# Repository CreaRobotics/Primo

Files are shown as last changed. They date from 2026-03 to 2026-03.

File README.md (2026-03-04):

<p allign="center">
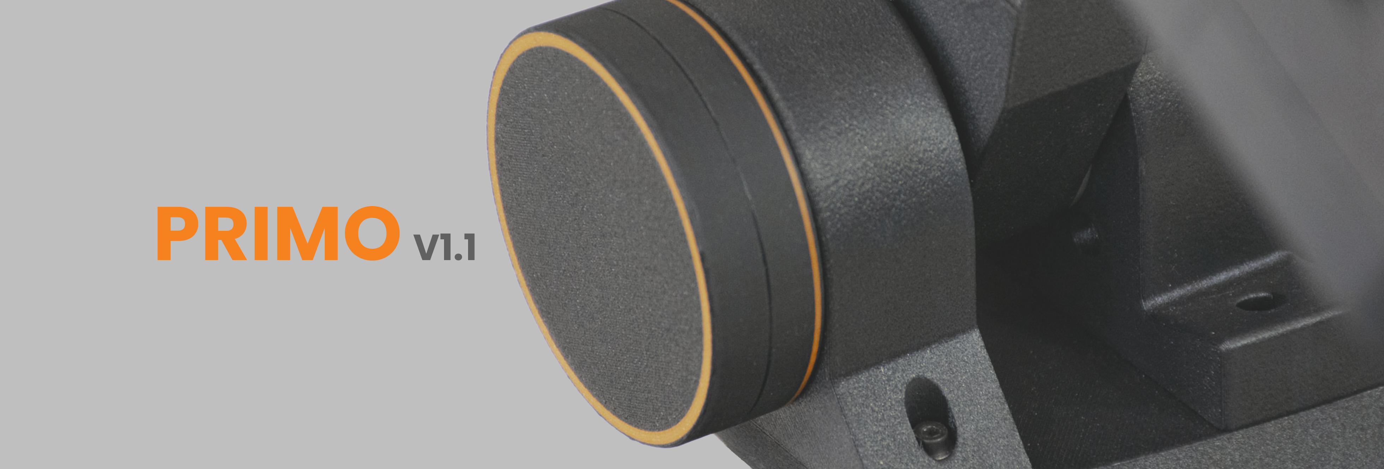
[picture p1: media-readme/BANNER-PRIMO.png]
Primo v1.1 Your first friendly robotic arm
 
</p>



# Manipolatore Antropomorfo 
Primo è il nostro manipolatore antropomorfo interamente stampato in 3d, progettato e realizzato da [Crea3D](https://www.crea3d.com/it/) per il settore STEM.
### 🦾Caratteristiche Principali <!-- (v0.0) -->

* **6 Gradi di Libertà (6 DOF):** Manipolatore a catena cinematica aperta, ispirato ai robot industriali.
* **Riduttori armonici:**  Garantiscono movimenti fluidi ad alta precisione.
* **Open Hardware:** File STL disponibili per la stampa 3D <!-- (consigliato PPS-CF o PLA rinforzato) -->.
* **Elettronica Accessibile:** Basato su Duet per una facile programmazione.
* **Compatibilità Software:** Supporta interfacce di programmazione software di simulazione professionali come **RoboDK**.
* **Modulare:** Facile da assemblare, riparare e modificare.

## 🔖Descrizione 

Primo è un braccio robotico a 6 assi open source interamente realizzato utilizzando la stampa 3d. Progettato a scopo educativo e formativo, con l' obiettivo di far scoprire il mondo della robotica a tutti, dando la possibilità di mettere in campo i concetti chiave

### 🔍 Cosa trovo in questa repository ?
 
 In questa repository troverai tutto il materiale necessario a ricreare Primo. Nelle varie cartelle troverai tutti i file CAD che permettono la stampa della struttura meccanica, le liste di componenti sia meccanici che elettrici, e i diagrammi delle connessioni e i software necessari.

* **01-CAD**: Contiene i file per la stampa 3D e i manuali di montaggio. 
* **02-BOM:** Liste componenti (BOM) meccanici ed elettrici
* **03-Digital Twin:** Contiene il modello gemello digitale per poterlo utilizzare con RoboDk. 
* **04-OS:** Contiene i file necessari a montare l'immagine dell'OS sul Raspberry Pi, precaricata con tutti i tool e le configurazioni necessarie.

### ⬇️ Dove posso trovare i file di stampa ?

Puoi trovare i file ufficiali anche sulle piattaforme:

👉 **[MakerWorld](https://makerworld.com/it/models/2473047-primo-v1-1-6-dof-robotic-arm#profileId-2715454)**

👉 **[Printables](https://www.printables.com/?lang=it)**

#### E se qualcosa va storto 🤕?
Se un pezzo stampato dovesse rompersi, nessun problema, grazie ai file a disposizione, puoi semplicemente ristamparlo in autonomia, senza dover attendere pezzi di ricambio o contattare l'assistenza.

Nella cartella 01-CAD troverai sia i file STL, ideali se vuoi sperimentare con parametri di stampa e materiali diversi,  già ottimizzati e pronti per essere stampati.

## 🚀 Per Iniziare

#### 📖 Documentazione

La documentazione completa, le guide di montaggio e la configurazione software, è disponibile qui: 

👉 **[Manuale Ufficiale PRIMO](https://crearobotics.github.io/PRIMO-Docs/cos_e_la_robotica/)**

#### 🛠️ Assemblaggio

Le istruzioni passo-passo per l'assemblaggio meccanico ed elettronico sono dettagliate nella nostra documentazione ufficiale.

* [Guida all'assemblaggio meccanico](https://crearobotics.github.io/PRIMO-Docs/)
* [Schema collegamenti elettronici](https://crearobotics.github.io/PRIMO-Docs/)

Oppure segui i video passo passo sul nostro canale [YouTube](https://www.youtube.com/@CreaRobotics).

## 🤝 Contribuisci

PRIMO è un progetto vivo. Sentiti libero di aprire *Issues* per segnalare problemi o *Pull Requests* per proporre miglioramenti ai file CAD o al codice. 

<!--Oppure scrivi una mail a: (mettere la mail)-->

# ⚠️ Avvertenze di Sicurezza 

Prima di assemblare o utilizzare PRIMO, leggere attentamente le seguenti direttive di sicurezza.
###### **Installazione Stabile:** Assicurarsi che il robot sia installato correttamente su una superficie solida e stabile, con spazio sufficiente attorno per evitare urti e collisioni durante il movimento. 

######  **Comportamento in Emergenza:** Il taglio dell'alimentazione o l'attivazione del pulsante di arresto di emergenza (E-Stop) possono causare un leggero abbassamento del braccio. Sebbene questo movimento sia ammortizzato, **non toccare il robot** mentre si attiva l'arresto di emergenza per evitare schiacciamenti o collisioni.

###### **Ambiente di Utilizzo:** Non utilizzare il robot in ambienti non idonei (es. all'aperto). Non installare PRIMO in ambienti umidi, vicino all'acqua o in ambienti pericolosi (es. presenza di gas infiammabili)..

###### **Calore e Temperatura:** Il robot e i motori generano calore durante il funzionamento. Non toccare o maneggiare il robot (in particolare la zona motori) durante l'operazione o subito dopo un uso prolungato: le alte temperature possono causare scottature. 

###### **Distanza di Sicurezza:** Quando PRIMO è attivo, mantenere una distanza di sicurezza dalle parti in movimento. Assicurarsi che il **pulsante di arresto di emergenza** sia sempre in una posizione facile e rapida da raggiungere per prevenire infortuni.

*Progettato e realizzato con il ❤️ da [Crea3d](https://www.crea3d.com/it/).*

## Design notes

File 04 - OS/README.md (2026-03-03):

## CONFIGURAZIONE
Nella cartella *Config* trovi tutto il necessario a configurare correttamente il Raspberry. Abbiamo predisposto una piccola guida e tutti i file necessari a crare correttamente una configurazione completa del softwere.

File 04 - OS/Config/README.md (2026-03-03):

# Configurazione

Questa procedura permette di installare la configurazione completa (configurazione base, macro e demo) su una microSD che contiene già Duet Web Control (DWC) e Duet Software Framework (DSF).

⚠️ Non eliminare la cartella `/www`, che contiene l’interfaccia web.

## Cosa ti serve

- La microSD della Duet
- Un PC con lettore microSD
- Il pacchetto di configurazione fornito

## Procedura guidata

### 1 - Spegni la Duet

Spegnere completamente l’alimentazione prima di rimuovere la microSD.

### 2 - Inserisci la microSD nel PC

- Rimuovi la microSD dalla Duet
- Inseriscila nel PC
- Se presente un file immagine, montalo per accedere al filesystem

### 3 - Naviga nel filesystem corretto

Se stai lavorando su una microSD con sistema Linux (DSF), segui questo percorso:

```
rootfs
 └── opt
     └── dsf
         └── sd
```

La cartella `sd` rappresenta la root effettiva della scheda SD vista da RepRapFirmware.

Apri quindi la cartella:

```
rootfs/opt/dsf/sd
```

### 4 - Verifica la struttura

All’interno della cartella `sd` dovresti trovare:

```
/sys
/macros
/gcodes
/www
```

⚠️ La cartella `/www` contiene Duet Web Control e non deve essere eliminata.

### 5 - Copia i file di configurazione

Dal pacchetto fornito:

- Copia la cartella `/sys`
- Copia la cartella `/macros`
- Copia la cartella `/gcodes` (se presente)

Incollale dentro:

```
rootfs/opt/dsf/sd
```

Quando richiesto:

✔ Conferma la sovrascrittura

❌ Non eliminare o modificare la cartella `/www`

### 6 - Smonta ed espelli in sicurezza

- Chiudi eventuali file aperti
- Espelli correttamente la microSD
- Rimuovila dal PC

### 7 - Reinserisci la microSD nella Duet

- Inserisci la scheda
- Accendi la Duet

Collegandoti via browser all’indirizzo IP della macchina troverai:

- Configurazione già attiva
- Macro operative disponibili
- File demo caricati
- Interfaccia DWC funzionante

## ⚠️ Controlli al primo avvio

Prima di eseguire programmi automatici:

- Verifica verso degli assi
- Controlla finecorsa
- Esegui piccoli movimenti manuali di test

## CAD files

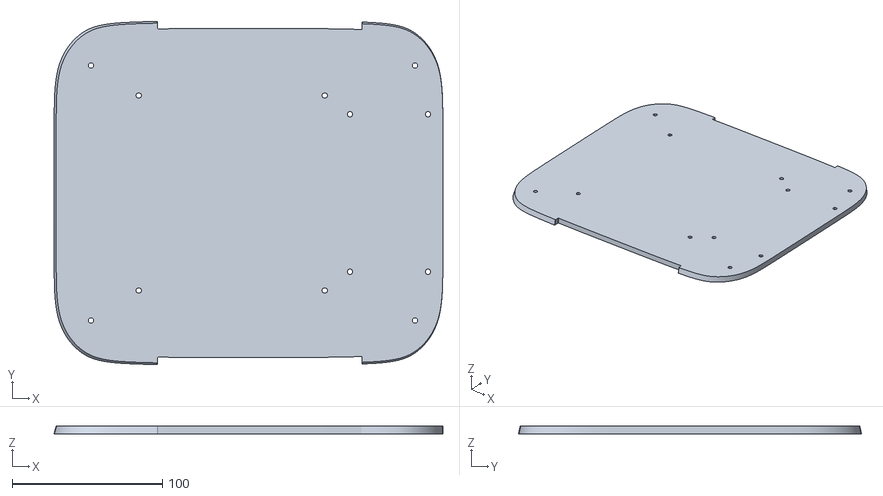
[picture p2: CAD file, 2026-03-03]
01 - CAD/02 - STL/01-BASE/STL/PRM_V11_AM3_BAS_002_R00.stl
259.3 x 228.8 x 5.00

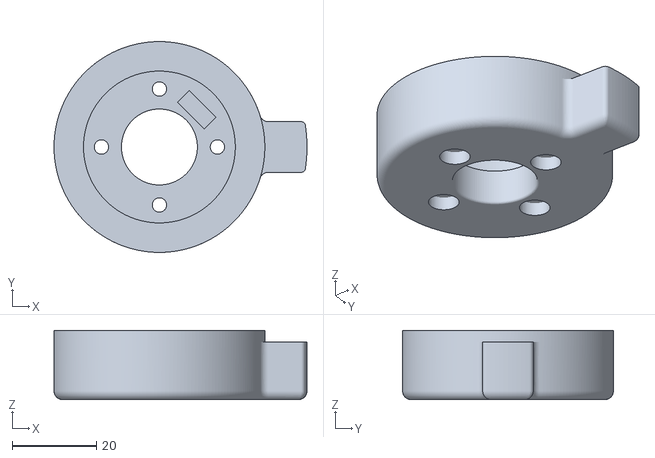
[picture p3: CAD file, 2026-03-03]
01 - CAD/02 - STL/02-SHOULDER/STL/PRM-V11-AM3-SHD-005-R00.stl
60.0 x 50.0 x 16.4

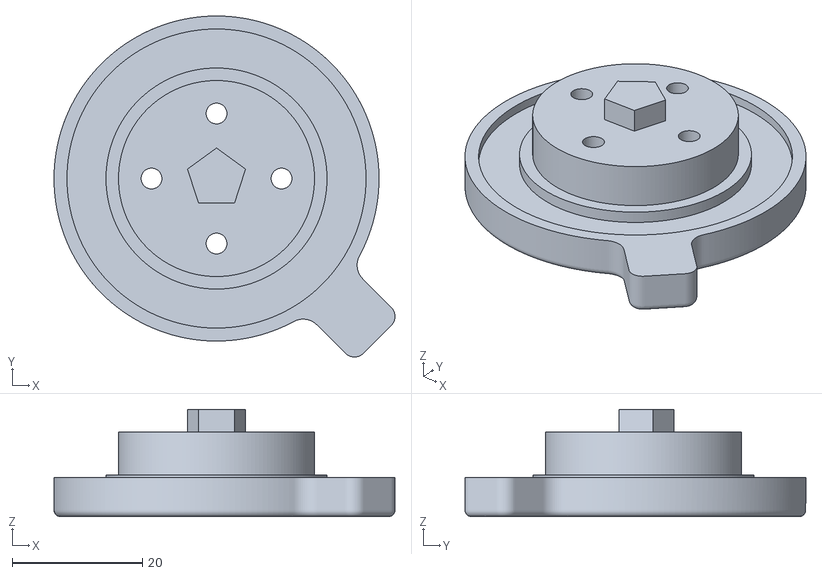
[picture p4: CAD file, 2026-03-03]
01 - CAD/02 - STL/03-ARM/STL/PRM-V11-AM3-ARM-009-R00.stl
52.4 x 52.5 x 16.5

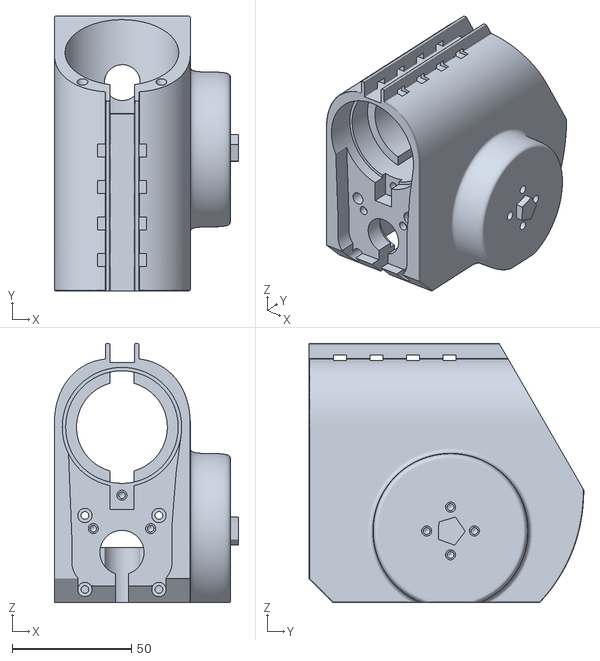
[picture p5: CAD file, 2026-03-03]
01 - CAD/02 - STL/04-ELBOW/STL/PRM-V11-AM3-ELB-001-R00.stl
77.2 x 115.0 x 108.5

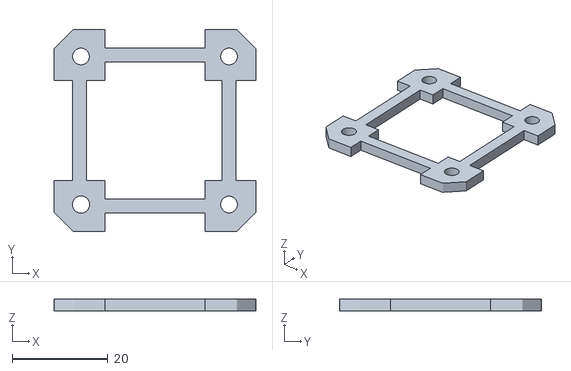
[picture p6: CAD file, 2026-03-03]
01 - CAD/02 - STL/05-FOREARM/STL/PRM_V11_AM3_FAM_003_R00.stl
42.3 x 42.3 x 2.50

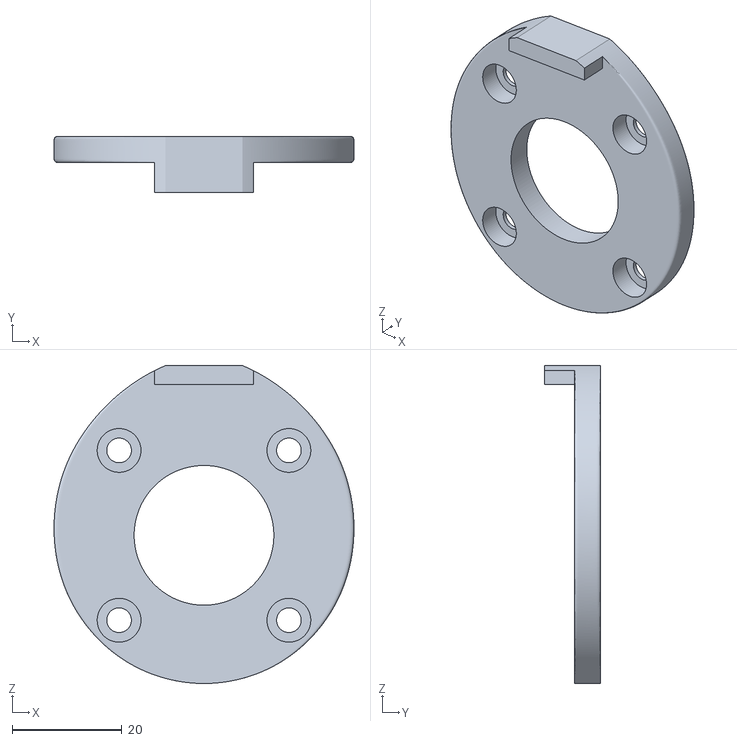
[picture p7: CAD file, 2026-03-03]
01 - CAD/02 - STL/06-WRIST/STL/PRM_V11_AM3_WRS_002_R00.stl
54.8 x 10.3 x 58.1

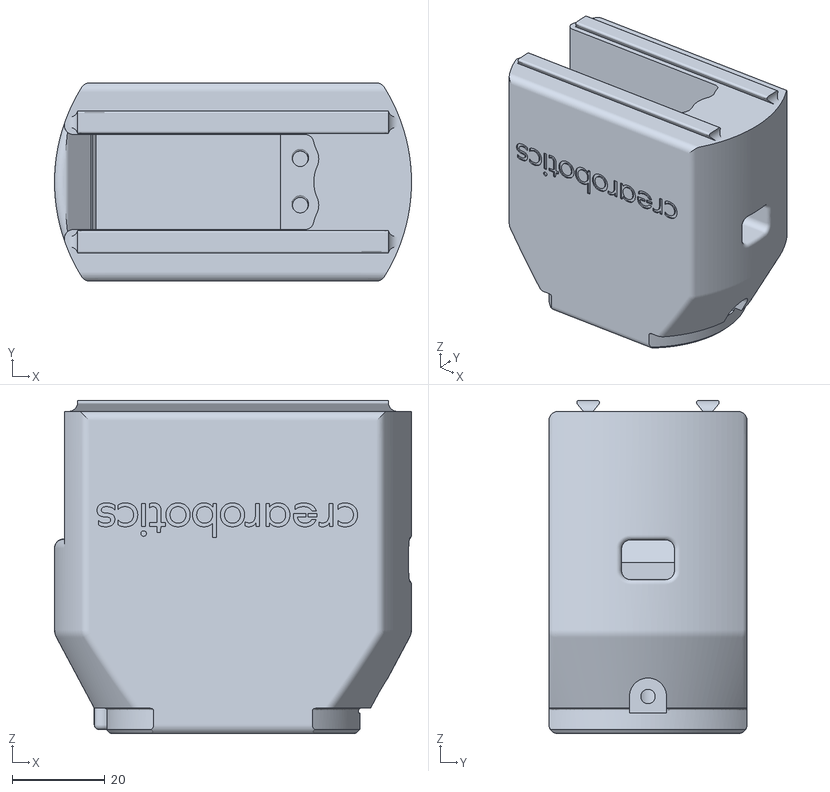
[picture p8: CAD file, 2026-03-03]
01 - CAD/02 - STL/07-EOT/STL/PRM-V11-AM3-EOT-001-R00.stl
77.0 x 42.8 x 71.9

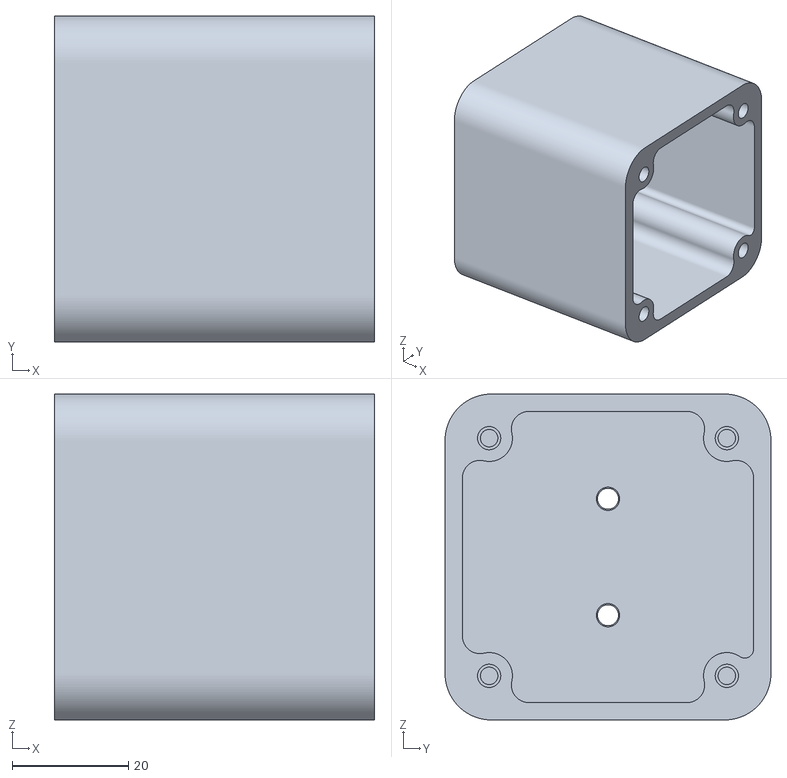
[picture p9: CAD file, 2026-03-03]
01 - CAD/02 - STL/01-BASE/STL/PRM_V11_AM3_BAS_011_R00.stl
55.0 x 56.0 x 56.0

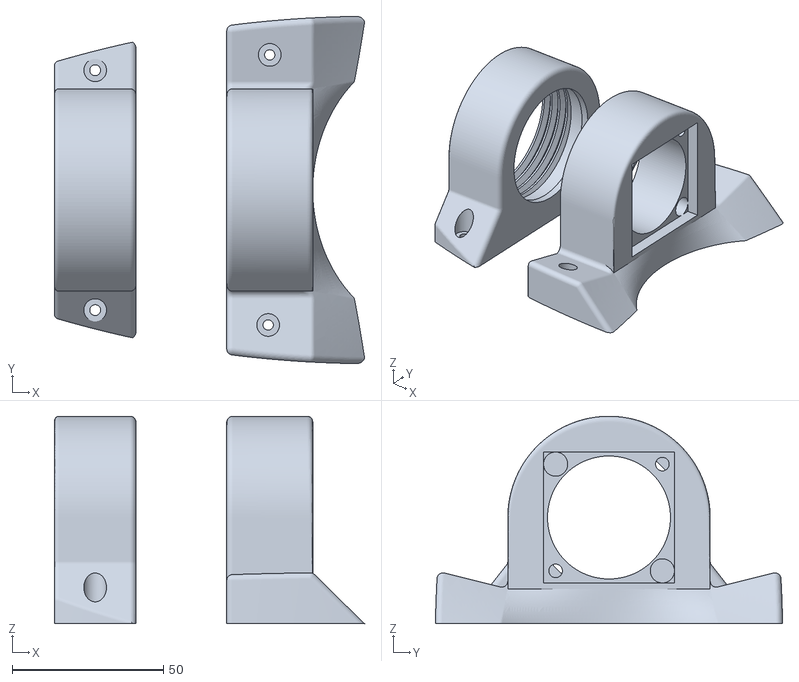
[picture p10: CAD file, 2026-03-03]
01 - CAD/02 - STL/02-SHOULDER/STL/PRM-V11-AM3-SHD-002-R00.stl
102.6 x 114.9 x 68.7

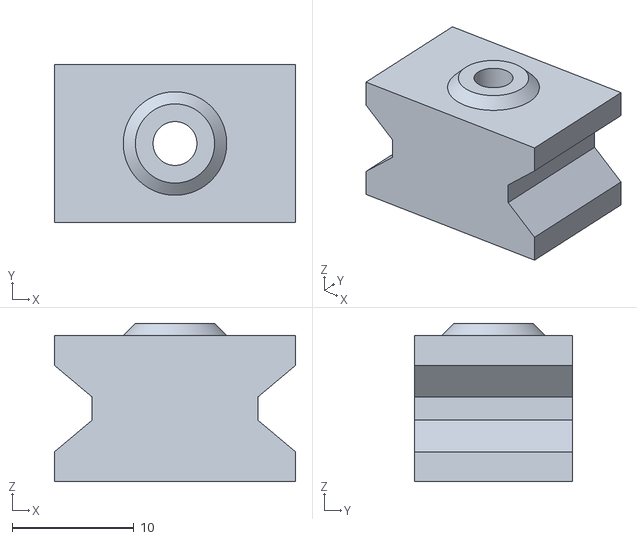
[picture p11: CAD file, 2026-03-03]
01 - CAD/02 - STL/03-ARM/STL/PRM-V11-AM3-ARM-007-R00.stl
19.8 x 13.0 x 13.0

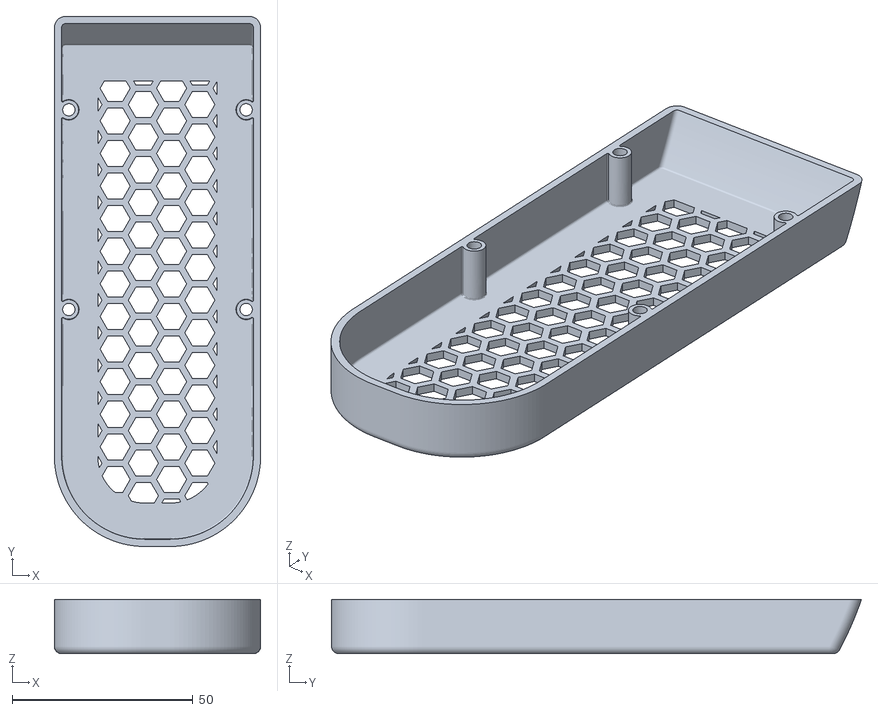
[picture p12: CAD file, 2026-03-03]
01 - CAD/02 - STL/05-FOREARM/STL/PRM_V11_AM3_FAM_005_R00.stl
57.0 x 146.4 x 15.0

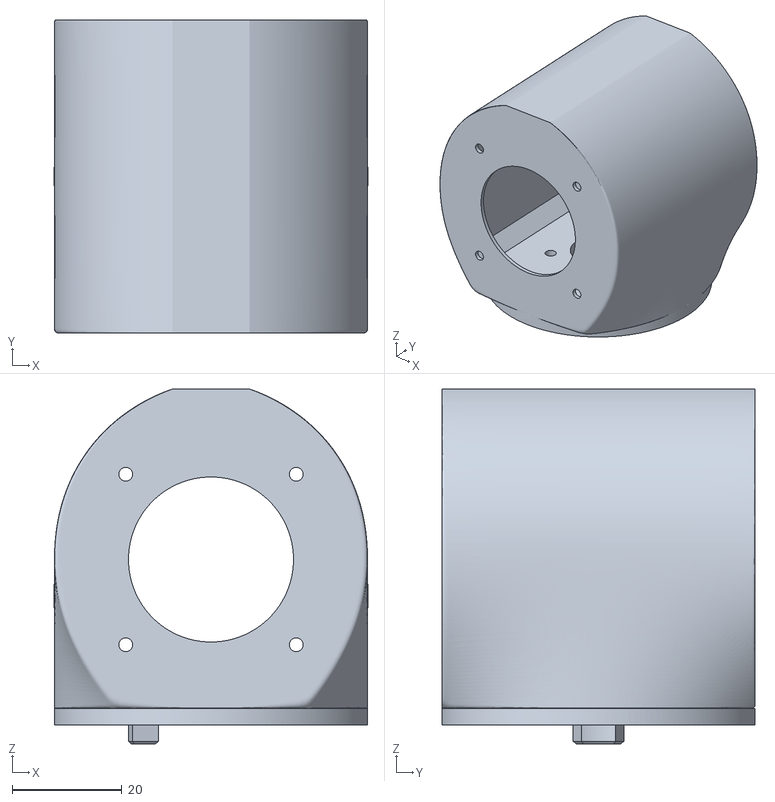
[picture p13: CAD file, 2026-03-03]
01 - CAD/02 - STL/06-WRIST/STL/PRM_V11_AM3_WRS_001_R00.stl
57.0 x 57.0 x 64.6

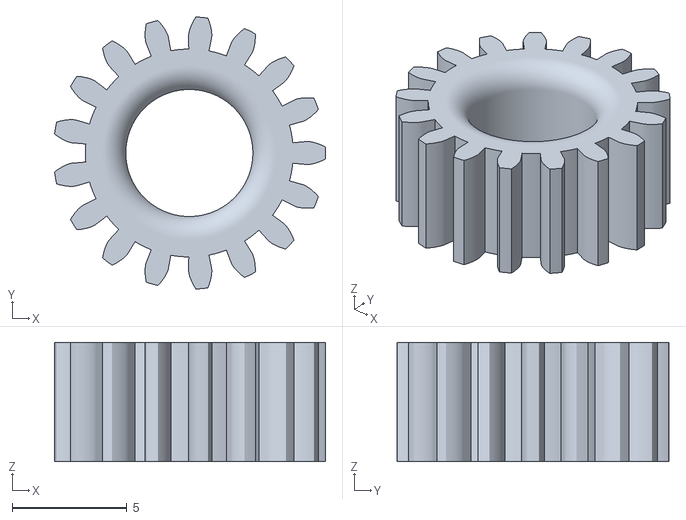
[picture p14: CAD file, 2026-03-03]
01 - CAD/02 - STL/07-EOT/STL/PRM-V11-AM3-EOT-002-R00.stl
11.8 x 11.8 x 5.20

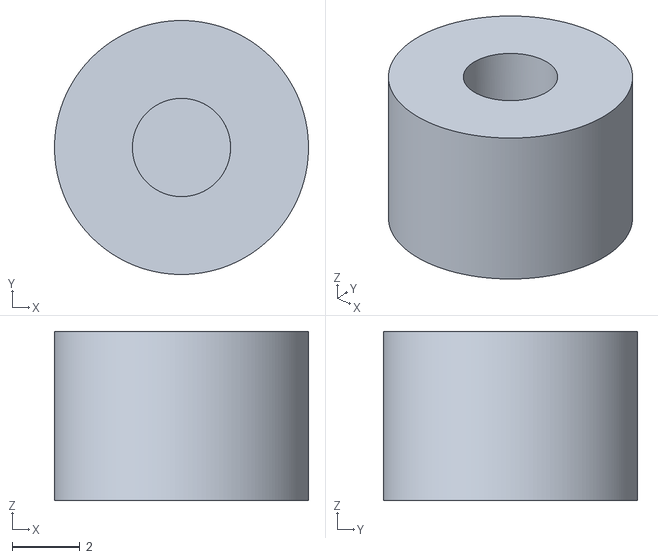
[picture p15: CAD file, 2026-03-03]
01 - CAD/02 - STL/01-BASE/STL/PRM_V11_AM3_BAS_009_R00.stl
7.50 x 7.50 x 5.00

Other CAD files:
01 - CAD/02 - STL/04-ELBOW/STL/PRM-V11-AM3-ELB-003-R00.stl
01 - CAD/02 - STL/02-SHOULDER/STL/PRM-V11-AM3-SHD-003-R00.stl
01 - CAD/02 - STL/03-ARM/STL/PRM-V11-AM3-ARM-003-R00.stl
01 - CAD/02 - STL/04-ELBOW/STL/PRM-V11-AM3-ELB-004-R00.stl
01 - CAD/02 - STL/01-BASE/STL/PRM_V11_AM3_BAS_003_R00.stl
01 - CAD/02 - STL/01-BASE/STL/PRM_V11_AM3_BAS_004_R00.stl
01 - CAD/02 - STL/01-BASE/STL/PRM_V11_AM3_BAS_005_R00.stl
01 - CAD/02 - STL/01-BASE/STL/PRM_V11_AM3_BAS_006_R00.stl
01 - CAD/02 - STL/01-BASE/STL/PRM_V11_AM3_BAS_007_R00.stl
01 - CAD/02 - STL/01-BASE/STL/PRM_V11_AM3_BAS_008_R00.stl
01 - CAD/02 - STL/01-BASE/STL/PRM_V11_AM3_BAS_010_R00.stl
01 - CAD/02 - STL/01-BASE/STL/PRM_V11_AM3_BAS_012_R00.stl
01 - CAD/02 - STL/01-BASE/STL/PRM_V11_AM3_BAS_013_R00.stl
01 - CAD/02 - STL/01-BASE/STL/PRM_V11_AM3_BAS_014_R00.stl
01 - CAD/02 - STL/01-BASE/STL/PRM_V11_AM3_BAS_015_R00.stl
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

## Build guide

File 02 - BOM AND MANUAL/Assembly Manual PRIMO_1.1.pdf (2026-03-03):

This document is released under the Crea Robotics Open Hardware License (CROHL) - v1.0 Crea Robotics - A division of Crea3D® - info@crearobotics.com

# Manuale di assemblaggio

# Robot - PRIMO 1.1

## Crea Robotics Open Hardware License (CROHL) – v1.0

© 2026 Crea Robotics – Crea 3D S.R.L.

This license governs the use of open hardware released by Crea Robotics.

### 1. Purpose

The Crea Robotics Open Hardware License (CROHL) is intended to encourage education, research, experimentation, repairability, and community-driven innovation, while protecting the commercial, industrial, and brand value of Crea Robotics hardware.

### 2. Definitions

Licensed Material: All files and documentation explicitly released under CROHL.
Licensor: Crea Robotics – Crea 3D S.R.L.
Licensee: Any individual or legal entity exercising rights under this license.
Commercial Use: Sale, distribution, or offering of complete products, kits, or services based on the Licensed Material.

### 3. Scope of Licensed Material

This license applies to mechanical CAD files (F3D, STEP, STL, 3MF), bills of materials (BOM), schematics, wiring diagrams, assembly documentation, demo files, and other materials explicitly marked as released under CROHL. Trademarks, logos, and product names are excluded.

### 4. Rights Granted

Subject to the terms of this license, the Licensor grants the Licensee a non-exclusive, worldwide, royalty-free right to access, study, modify, manufacture, assemble, and use the Licensed Material for personal, educational, research, and internal non-commercial purposes.

### 5. Redistribution and Derivative Works

Redistribution of original or modified Licensed Material is permitted only if: (a) this license is included in full; (b) modifications are clearly documented; (c) attribution to Crea Robotics is maintained; (d) all derivatives are released under CROHL.

### 6. Commercial Restrictions

Without a separate written commercial agreement, the Licensee may not sell, distribute, or offer complete machines, kits, OEM products, or commercial services based on the Licensed Material, nor claim official compatibility or endorsement by Crea Robotics.

### 7. Trademarks

This license does not grant permission to use any trademarks, logos, or product names of Crea Robotics, including but not limited to the name PRIMO.

### 8. Patent License

The Licensor grants a non-exclusive, royalty-free patent license necessary to exercise the rights granted under this license. This patent license terminates if the Licensee initiates patent litigation against the Licensor relating to the Licensed Material.

### 9. Artificial Intelligence Restriction

The Licensed Material may not be used for automated data extraction, dataset generation, or training of artificial intelligence or machine learning models without explicit written permission.

### 10. Disclaimer of Warranty

The Licensed Material is provided “AS IS”, without warranty of any kind. The Licensee assumes all risks related to safety, regulatory compliance, and use.

### 11. Limitation of Liability

In no event shall Crea Robotics be liable for any damages arising from the use or inability to use the Licensed Material.

### 12. Termination

This license is automatically terminated if its terms are violated. Upon termination, the Licensee must cease distribution of the Licensed Material.

### 13. Governing Law

This license shall be governed by and interpreted in accordance with the laws of Italy and the European Union.

### END OF LICENSE

## Prefazione

## _____________________________________________________

Il progetto “PRIMO” nasce con l’obiettivo di avvicinare studenti, maker e appassionati al mondo della robotica industriale attraverso un’esperienza concreta, pratica e accessibile. Si tratta di un braccio robotico educativo a 6 assi completamente motorizzato, progettato per simulare i movimenti e la logica di funzionamento dei manipolatori robotici utilizzati nei contesti produttivi reali. PRIMO non è soltanto un dispositivo da utilizzare, ma un sistema da comprendere: ogni fase della sua costruzione è parte integrante del processo di apprendimento. Il robot è stato concepito per essere intuitivo, modulare e facilmente assemblabile, permettendo anche a utenti senza precedenti esperienze, di affrontare in modo guidato tutte le fasi di montaggio: l’utente impara a leggere schemi tecnici, riconoscere componenti meccanici ed elettronici, comprendere le interazioni tra struttura, attuazione e controllo, e verificare il corretto funzionamento del sistema. PRIMO sfrutta estensivamente la stampa 3D come strumento progettuale e didattico. Le parti strutturali sono pensate per essere realizzate direttamente dall’utente, consentendo un’elevata personalizzazione del robot e dimostrando il reale valore del “costruirlo in casa”. Questa scelta progettuale riduce costi e complessità, mantenendo al contempo un elevato livello tecnico e offrendo la possibilità di adattare il braccio robotico a esigenze specifiche, attività educative o sperimentazioni di laboratorio.

Per i componenti più sollecitati viene impiegato PPS-CF (Polifenilene Solfuro rinforzato con fibre di carbonio), un materiale ad alte prestazioni che combina leggerezza, rigidità strutturale, resistenza meccanica e durabilità. L’utilizzo di questo polimero avanzato permette al robot di mantenere stabilità e precisione nei movimenti, caratteristiche fondamentali nei sistemi robotici multi-asse. Il sistema è inoltre progettato per essere compatibile con RoboDK e con diversi linguaggi di programmazione, consentendo di affrontare sia la parte meccanica sia quella software della robotica. Questo manuale accompagna passo dopo passo l’utente durante l’assemblaggio del robot. Ogni operazione è pensata non solo per portare alla realizzazione del dispositivo, ma anche per sviluppare manualità tecnica, capacità di problem-solving e consapevolezza ingegneristica. Al termine del percorso, il partecipante non avrà semplicemente montato un robot: avrà compreso come e perché funziona.

_______________________________________________________________________________________

## Sommario

# 1. Introduzione

Benvenuto/a al manuale di assemblaggio di PRIMO, il braccio robotico a 6 assi progettato per l’apprendimento pratico della robotica. Questo documento è stato realizzato per guidarti passo dopo passo nell’assemblaggio del tuo kit, con istruzioni chiare, illustrazioni dettagliate e consigli pratici per garantire un’esperienza completa. Il manuale è pensato per studenti, insegnanti, maker e appassionati di tecnologia, con l’obiettivo di rendere l’apprendimento della robotica accessibile e stimolante. Non è necessario essere esperti: ogni fase è descritta in modo da facilitare sia chi si approccia per la prima volta sia chi ha già esperienza con bracci robotici o sistemi meccanici complessi.

Di seguito verrà descritta e illustrata allo stesso tempo, la procedura corretta per la realizzazione del robot PRIMO. In particolare, verranno spiegate le modalità di assemblaggio, fornendo indicazione precisa su componenti da utilizzare in maniera cronologica, dalle parti stampate in 3D ai componenti meccanici, ai componenti elettrici. Tutti i componenti del kit, dalle parti meccaniche ai servomotori, fino agli elementi elettronici, sono elencati nelle sezioni successive. Le parti stampate possono essere facilmente riprodotte in caso di danneggiamento, mentre i pezzi in PPS-CF richiedono una stampante 3D compatibile con questo materiale speciale.

La sicurezza è fondamentale: durante l’assemblaggio, ti invitiamo a seguire attentamente le istruzioni, a utilizzare gli strumenti in modo corretto e a prestare attenzione ai componenti elettronici e meccanici.

Questo manuale non è solo una guida tecnica, ma anche un invito a esplorare, sperimentare e personalizzare il tuo braccio robotico. Ogni passo ti avvicina alla comprensione dei principi fondamentali della robotica, stimolando la creatività e la capacità di risolvere problemi in modo pratico.

Buon lavoro e buona scoperta di PRIMO!

# 2. Attrezzi essenziali per l’assemblaggio

Per assemblare PRIMO in modo efficace e sicuro, è necessario disporre di alcuni strumenti di base. Tra questi, vi sono alcuni che risultano essere strettamente necessari, e altri aggiuntivi che possono facilitare in parte l’intero processo di assemblaggio.

Alcuni di questi comprendono: chiavi a brugola di varie misure, cacciaviti a testa piatta e a croce, pinze e taglierini per rifiniture, oltre a una superficie di lavoro stabile e ben illuminata. Avere a portata di mano questi attrezzi ti permetterà di seguire le istruzioni passo dopo passo senza interruzioni, garantendo un montaggio preciso e ordinato.

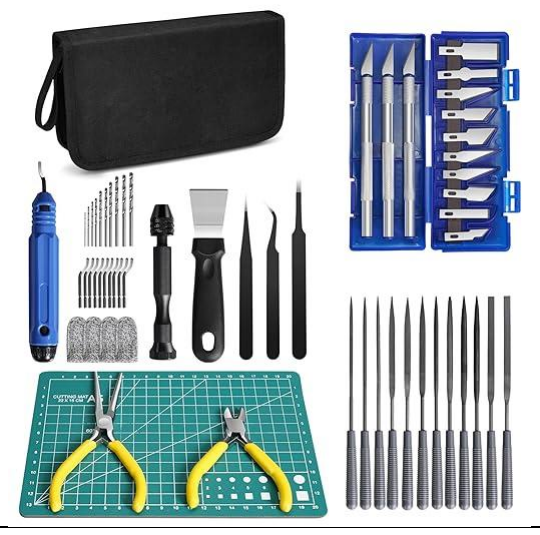
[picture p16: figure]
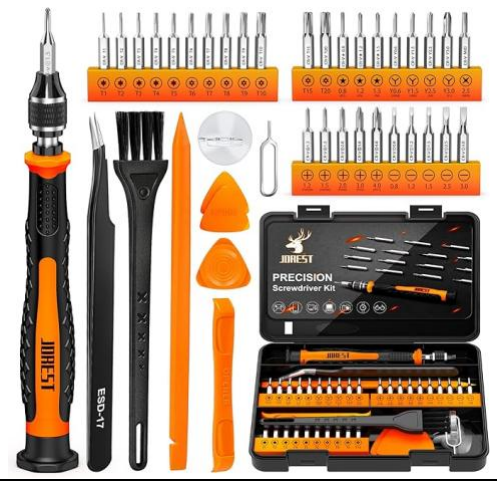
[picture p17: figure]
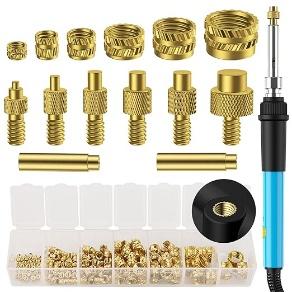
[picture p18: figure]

# 3. Base

La base costituisce il primo sottosistema funzionale. L’assemblaggio completo sarà costituito da 8 steps.

## 3.1 Base_01

Gli elementi necessari in questa fase sono i seguenti:

- Base
- Vite M3 x 16 (6x)
- PCB support
- Inserto filettato M3 (6x)
- 40x40 PC fan
- DC fan socket

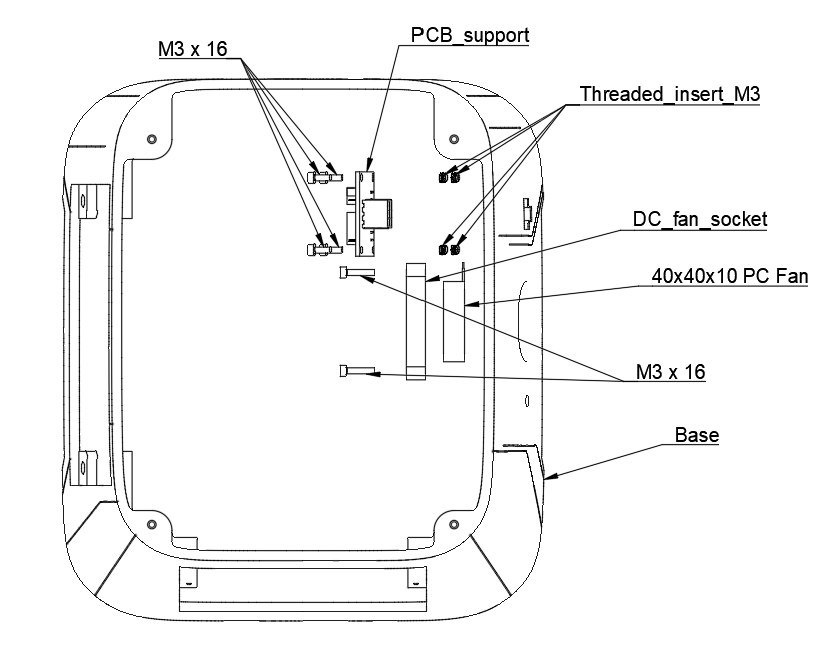
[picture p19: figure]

## 3.2 Base_02

Gli elementi necessari in questa fase sono i seguenti:

- Base plate
- Vite M3x16 (4x)
- Vite M3x12 (4x)
- Inserto filettato M3 (4x)
- PCB spacer (2x)
- Duet 6HC main board DIN

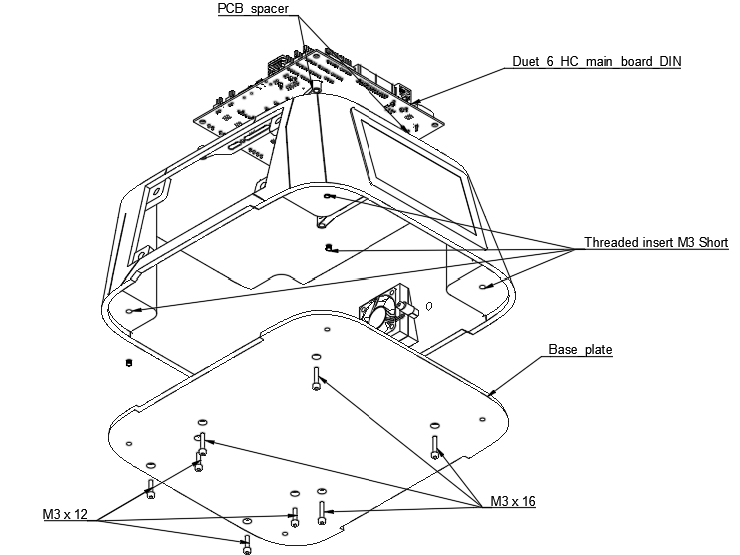
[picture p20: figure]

## 3.3 Base_03

Gli elementi necessari in questa fase sono i seguenti:

- 5_in_DSI_LCD
- Vite M2x10 (4x)
- Vite M2.5x6 (4x)
- Hex_nut_M3_JIS_Class_1 (8x)
- Power_supply

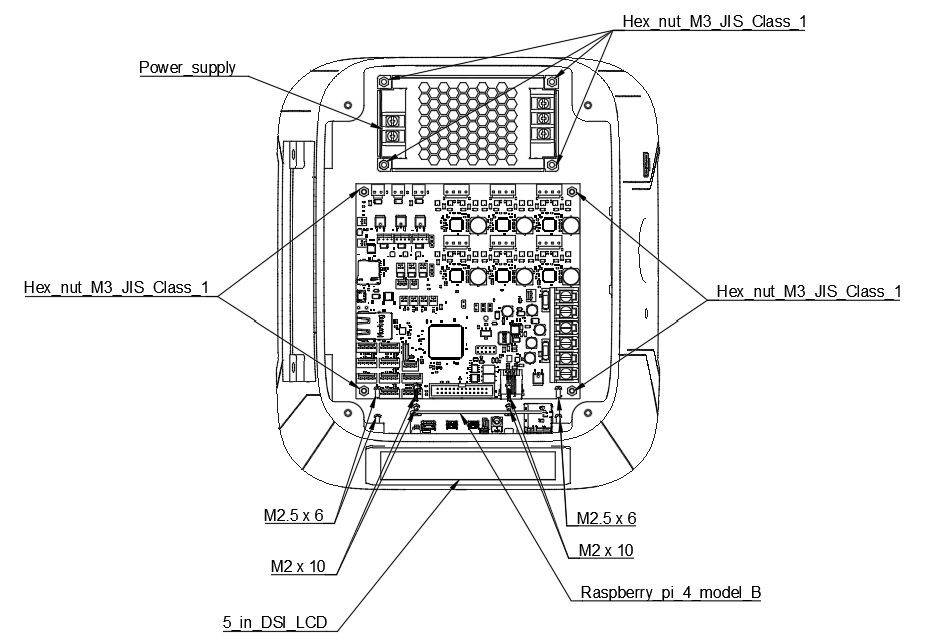
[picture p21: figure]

## 3.4 Base_04

Gli elementi necessari in questa fase sono i seguenti:

- Magnete 3 mm (8x)
- Inserto filettato M3 (4x)

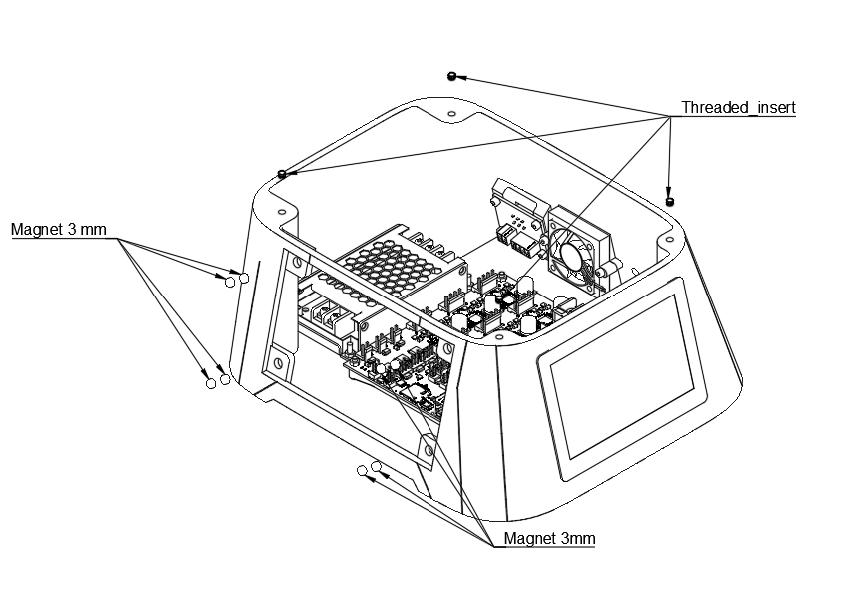
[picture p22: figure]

## 3.5 Base_05

Gli elementi necessari in questa fase sono i seguenti:

- Stepper_45_Ncm
- Freno elettromagnetico
- Vite M3x14 (4x)
- Top pulley belt guide
- Belt cylindrical guide
- HNKK5-3 nut
- Vite M3x12
- Vite M3x14 (4x)
- Low pulley belt guide
- Hex nuts M3 JIS Class 1
- Bearing NSK HR32907J
- Shaft support
- Inserti filettati M3 (4x)
- Mechanical stop switch
- Vite M3 x 14 (2x)

## 3.6 Base_06

Gli elementi necessari in questa fase sono i seguenti:

- Vite M3x10 (4x)
- Belt pulley (2x)
- M3x20
- Grub screw M3
- Pulley HTD3M 15T
- Belt J1 381
- Bearing NSK HR32907J
- Vite M3x25 (4x)
- Upper carter

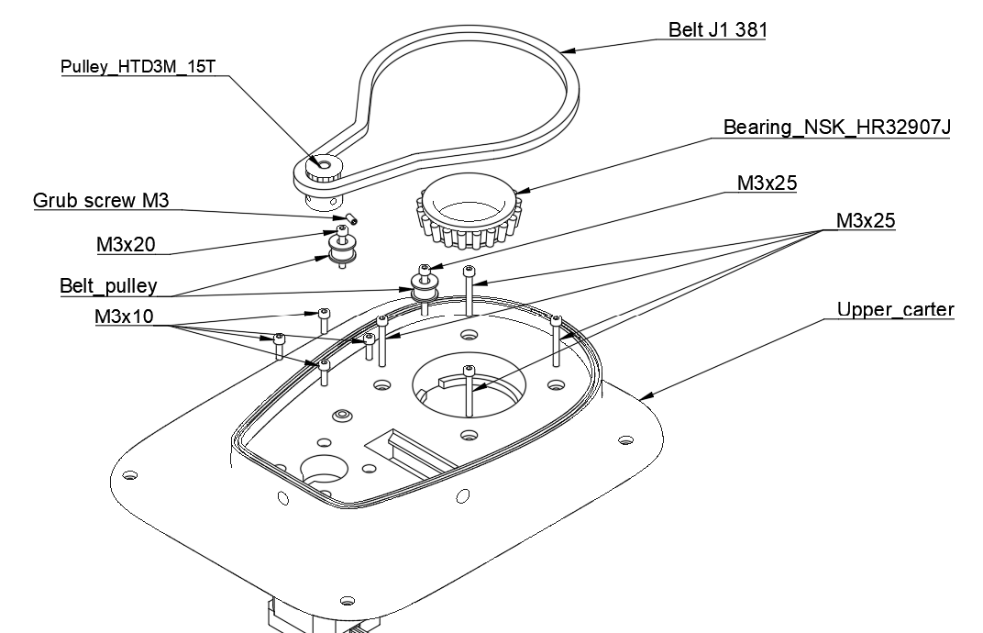
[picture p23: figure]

## 3.7 Base_07

Gli elementi necessari in questa fase sono i seguenti:

- Vite M3x20 (4x)
- Rondella M3 (4x)
- Plexiglass base
- Top cover carter 1
- Top cover carter 2
- Lateral door

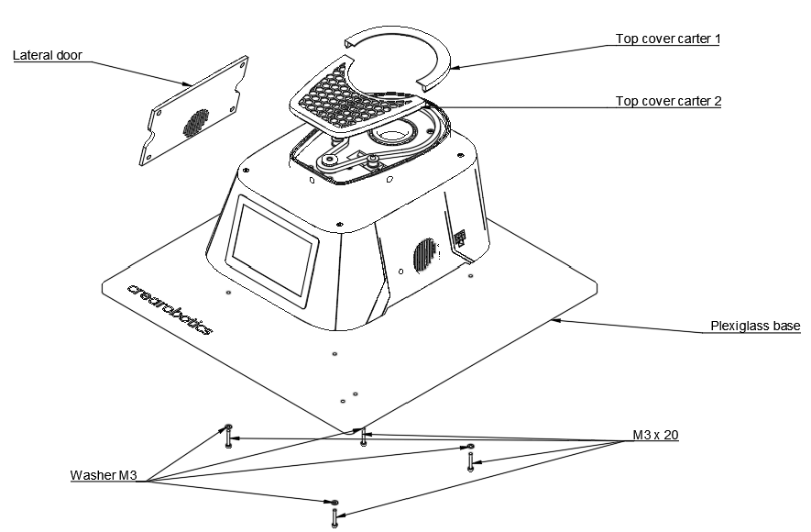
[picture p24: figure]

## 3.8 Base_08

Gli elementi necessari in questa fase sono i seguenti:

- Vite M3x12 (2x)
- Inserti filettati M3(6x)
- Emergency button
- Bottom emergency carter
- Top emergency carter
- Vite M3x12 (4x)

# 4. Shoulder

La spalla costituisce il secondo sottosistema funzionale. L’assemblaggio completo sarà costituito da 4 step.

## 4.1 Shoulder_01

Gli elementi necessari in questa fase sono i seguenti:

- Lower shoulder
- Washer M3(4x)
- Vite M3x16 (4x)
- Inserti filettati M3 (4x)

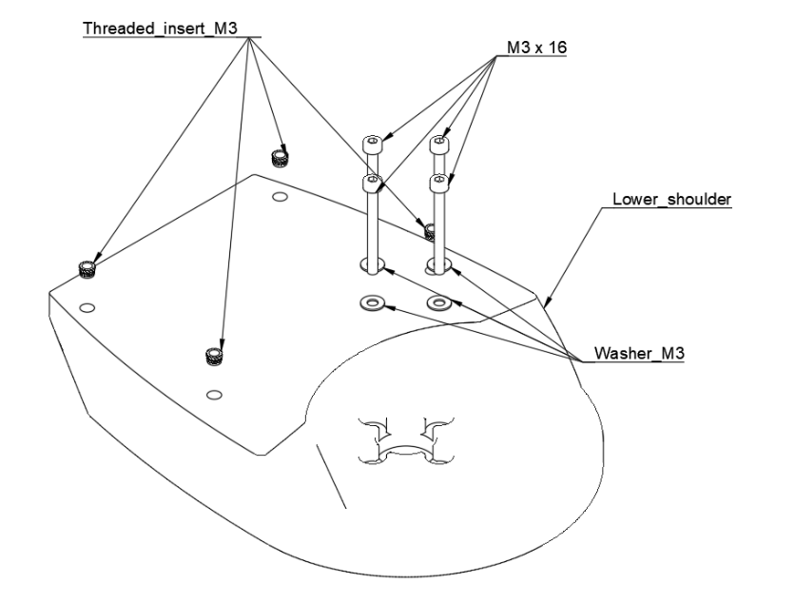
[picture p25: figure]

## 4.2 Shoulder_02

Gli elementi necessari in questa fase sono i seguenti:

- Bottom pulley
- Vertical shaft
- Threaded insert M3 (4x)
- Shaft_cap
- Vite M3x16 (4x)

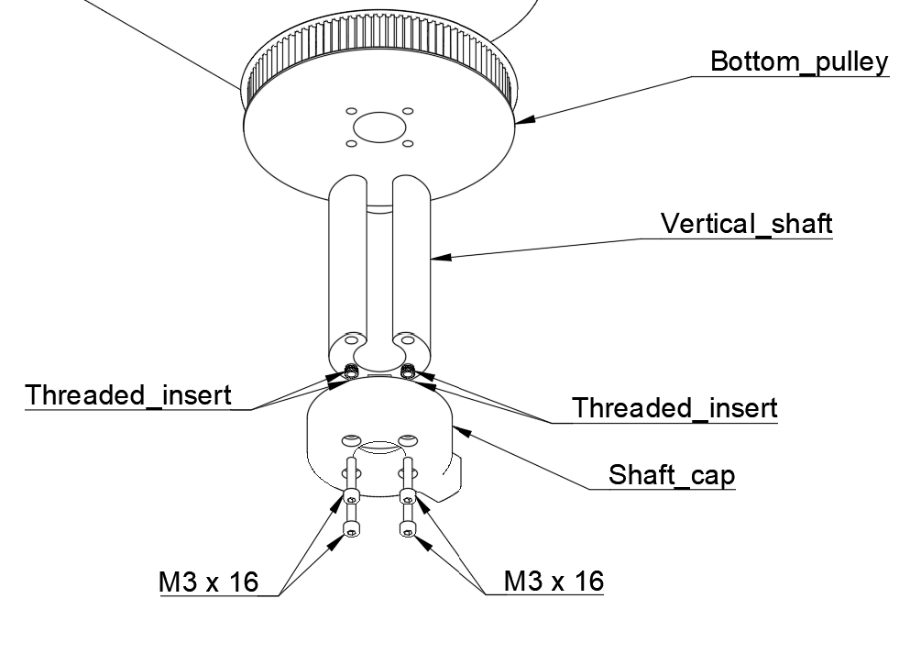
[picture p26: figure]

## 4.3 Shoulder_03

Gli elementi necessari in questa fase sono i seguenti:

- Upper shoulder
- M4x16 (2x)
- Skf_bearing_61808
- Screw_cap
- M3x16 (4x)
- Washer M3
- Harmonic_reducer_80:1

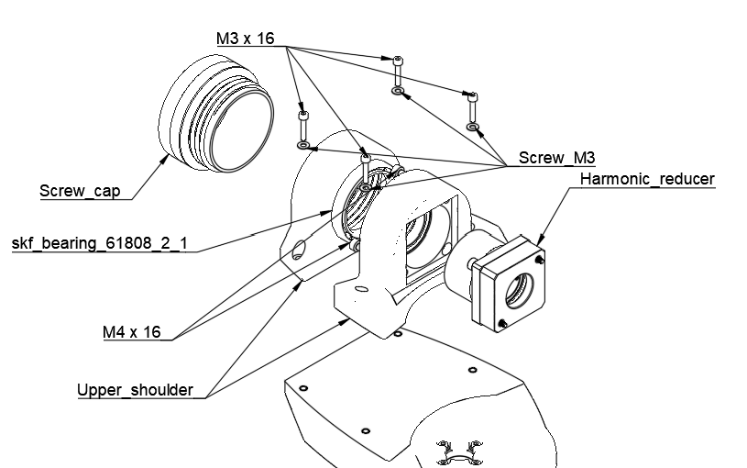
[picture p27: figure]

## 4.4 Shoulder_04

Gli elementi necessari in questa fase sono i seguenti:

- Stepper_17HS16-2004D
- Electromagnetic_brake_SWB-01
- Stepper_cover_65_Ncm_prt_1
- Stepper_PCB
- Stepper_cover_65_Ncm_prt_2
- Vite M3x90

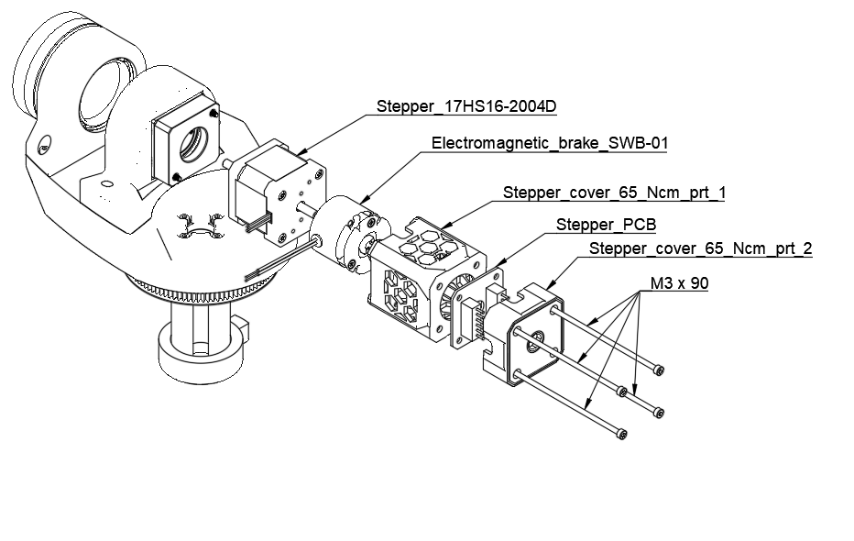
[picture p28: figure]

# 5. Arm

Il braccio costituisce il terzo sottosistema funzionale. L’assemblaggio completo sarà costituito da 6 steps.

## 5.1Arm_01

Gli elementi necessari in questa fase sono i seguenti:

- Inserto filettato M3 (6x)
- Inserto filettato M3 (2x)

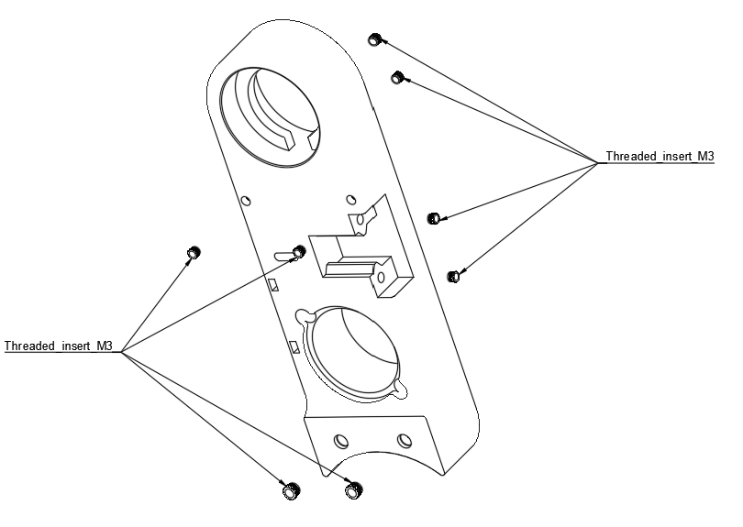
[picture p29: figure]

## 5.2Arm_02

Gli elementi necessari in questa fase sono i seguenti:

- Bearing_SKF_6906
- HNKK5-3
- Sliding_guide
- Hex_nut_M3_JIS_class1
- Tensioner_support
- Vite M3x16 (2x)
- Vite Mex12
- HNKK5-3
- Tensioner_space

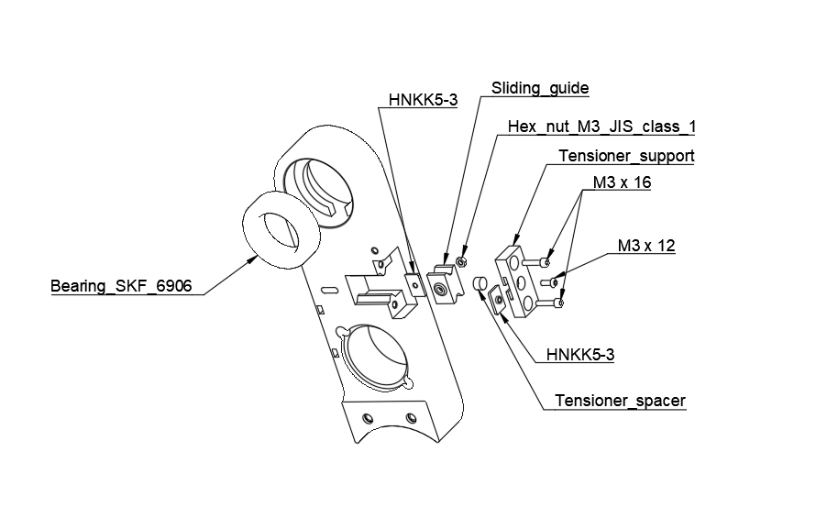
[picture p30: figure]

## 5.3Arm_03

Gli elementi necessari in questa fase sono i seguenti:

- Bearing_SKF_6906
- 55°armonic_reducer_pulley
- Washer M3 (4x)
- Vite M3x50
- 55°_mechanical_stop
- Vite M3x14

## 5.4Arm_04

Gli elementi necessari in questa fase sono i seguenti:

- Washer M3 (2x)
- Hex_nut_M3_JIS_class_1
- Top arm pulley
- Belt_pulley
- Vite M3x16 (2x)
- 42_teeth_stepper_pulley
- Vite M3x16 (6x)
- Washer M3 (6x)

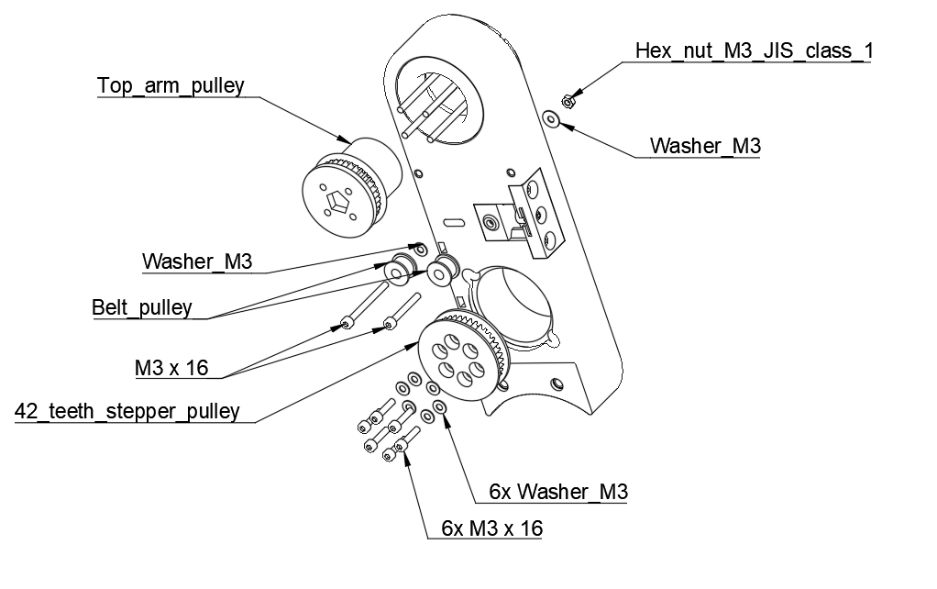
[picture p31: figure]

## 5.5Arm_05

Gli elementi necessari in questa fase sono i seguenti:

- Upper_arm_carter
- Vite M3x16 (8x)
- Washers M3 (8x)
- M4x16 (2x)
- Lower_side_arm

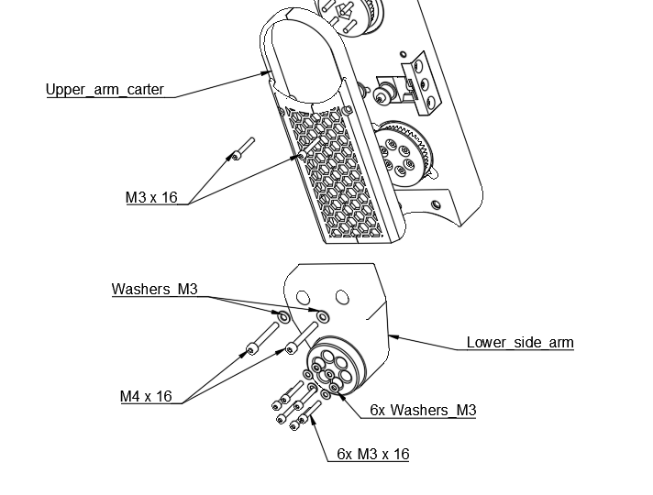
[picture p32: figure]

## 5.6 Arm_06

Gli elementi necessari in questa fase sono i seguenti:

- Vite M4x14 (2x)
- Harmonic_reducer
- Stepper_17HS16-2004D
- Electromagnetic_brake
- Stepper_cover_65_Ncm_prt_1
- Stepper_PCB
- Stepper_cover_65_Ncm_prt_2
- Vite M3x90

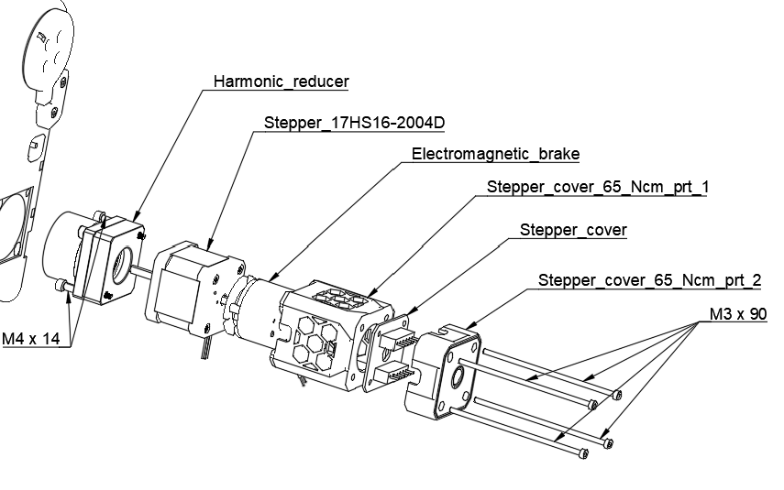
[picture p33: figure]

# 6. Elbow

Il Gomito costituisce il quarto sottosistema funzionale. L’assemblaggio completo sarà costituito da 2 steps.

## 6.1 Elbow_01

Gli elementi necessari in questa fase sono i seguenti:

- Vite M3x12 (2x)
- Elbow_carter
- Bearing_6906

## 6.2 Elbow_02

Gli elementi necessari in questa fase sono i seguenti:

- Inserto filettato M3 (6x)
- Washer M3 (2x)
- Bearing_623ZZ (4x)
- 12_teeth_pulley
- Grub_screw_M3
- Mechanical_stop
- Vite M3x12
- Bearing_6906

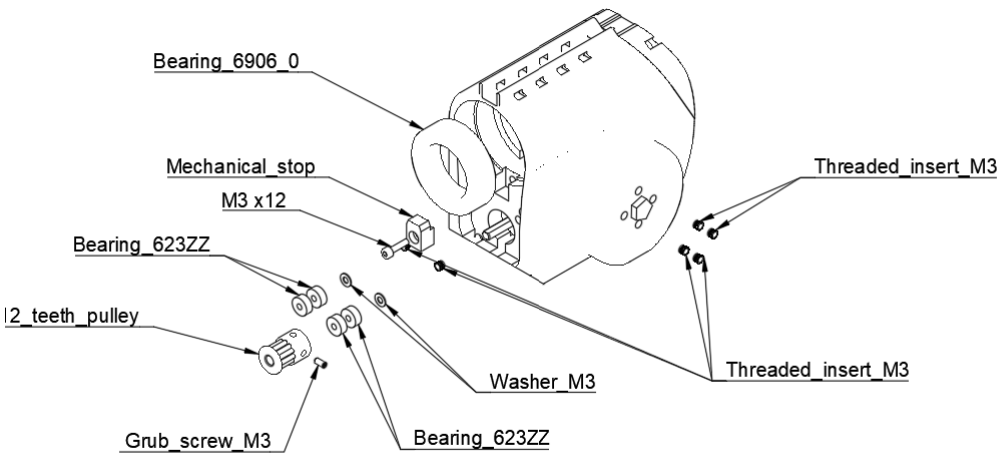
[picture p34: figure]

# 7. Forearm

L’avambraccio costituisce il quinto sottosistema funzionale. L’assemblaggio completo sarà costituito da 4 steps.

## 7.1 Forearm_01

Gli elementi necessari in questa fase sono i seguenti:

- Forearm_case
- Thrust_bearing
- Mechanical_stop
- Bearing_6906
- Vite M3x16

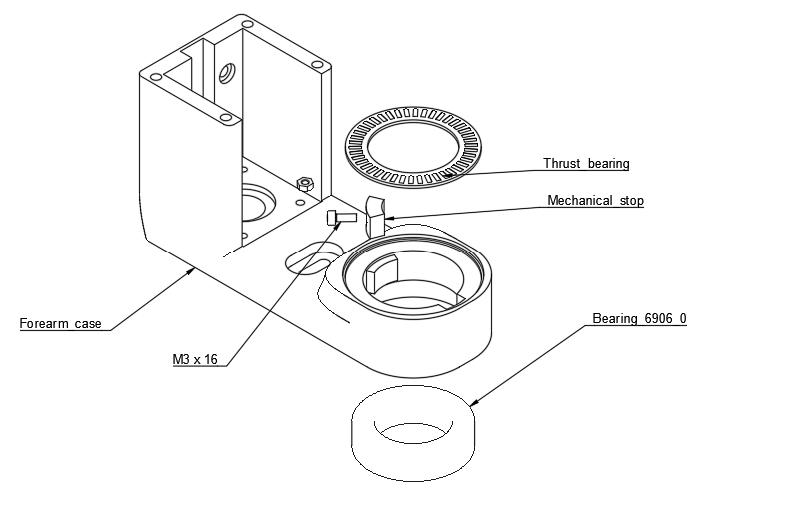
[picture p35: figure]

## 7.2 Forearm_02

Gli elementi necessari in questa fase sono i seguenti:

- Inserti filettati M3 (4x)
- 12_teeth_pulley
- Vite M3x16
- Large_washer_M3x16 (6x)
- Bearing_623ZZ (4x)
- Forearm_pulley_shaft
- Vite M3x16 (4x)

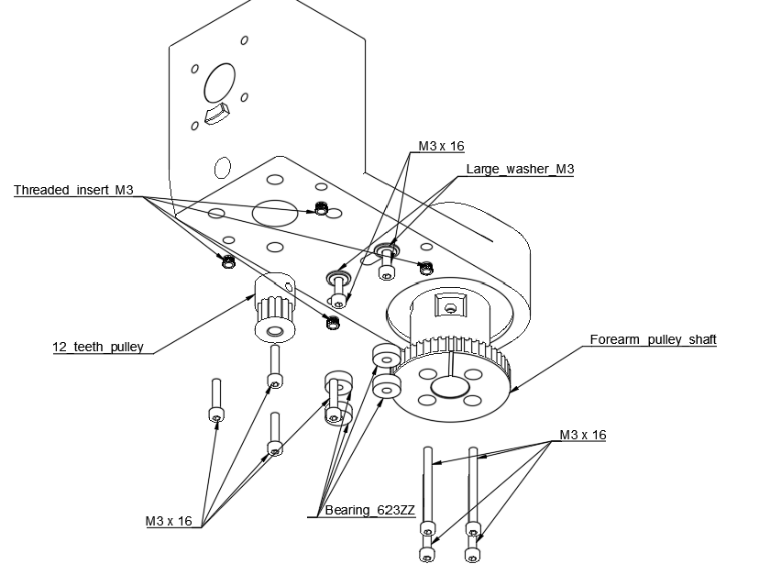
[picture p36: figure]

## 7.3 Forearm_03

Gli elementi necessari in questa fase sono i seguenti:

- PCB_assembly
- Stepper_17HS16-2004S1
- Stepper_spacer

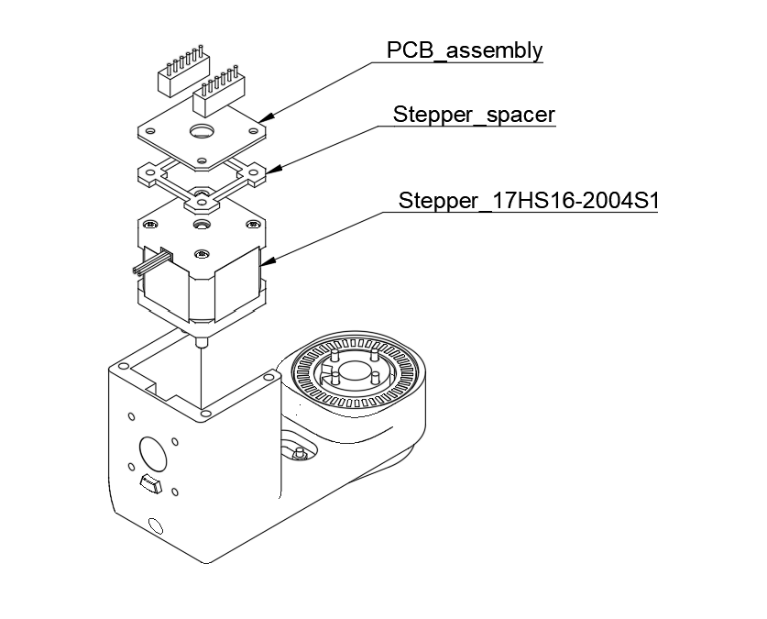
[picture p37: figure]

## 7.4 Forearm_04

Gli elementi necessari in questa fase sono i seguenti:

- Viti M3x16 (4x)
- Forearm_shaft
- Threaded_insert_M3 (4x)
- Stepper_forearm_carter
- Viti M3x10 (4x)
- Forearm_carter
- Viti M3x20
(4x)

# 8. Wrist

L’avambraccio costituisce il sesto sottosistema funzionale. L’assemblaggio completo sarà costituito da 1 step.

## 8.1 Wrist_01

Gli elementi necessari in questa fase sono i seguenti:

- Wrist_flange
- Wrist_base
- Stepper_17HS16-2004S1

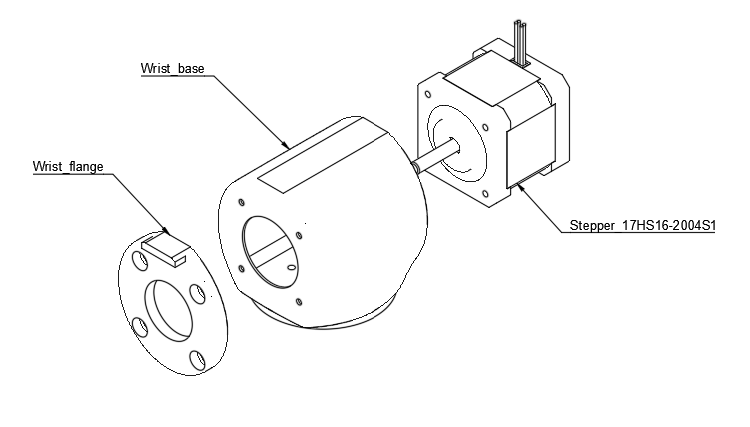
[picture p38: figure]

# 9. Gripper

L’avambraccio costituisce il settimo e ultimo sottosistema funzionale. L’assemblaggio completo sarà costituito da 1 step.

## 9.1 Gripper_01

Gli elementi necessari in questa fase sono i seguenti:

- Beak (2x)
- Case
- Viti M4x8
- MG996R
- Gear

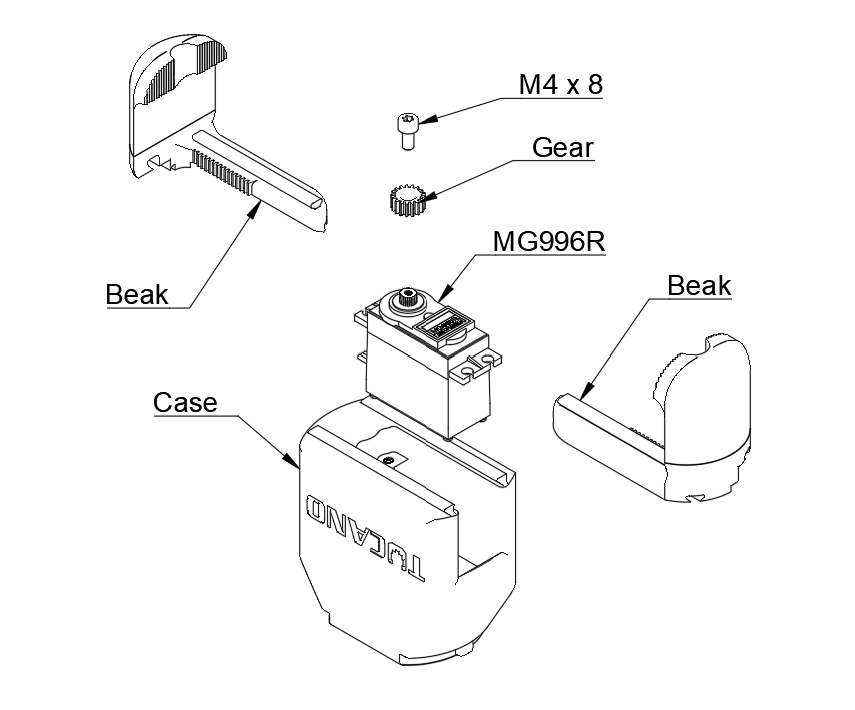
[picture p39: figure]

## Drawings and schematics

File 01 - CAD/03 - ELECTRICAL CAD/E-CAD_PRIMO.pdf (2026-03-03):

V1.1 ⁴⁸V | GND_AL 1.1 | 1.2

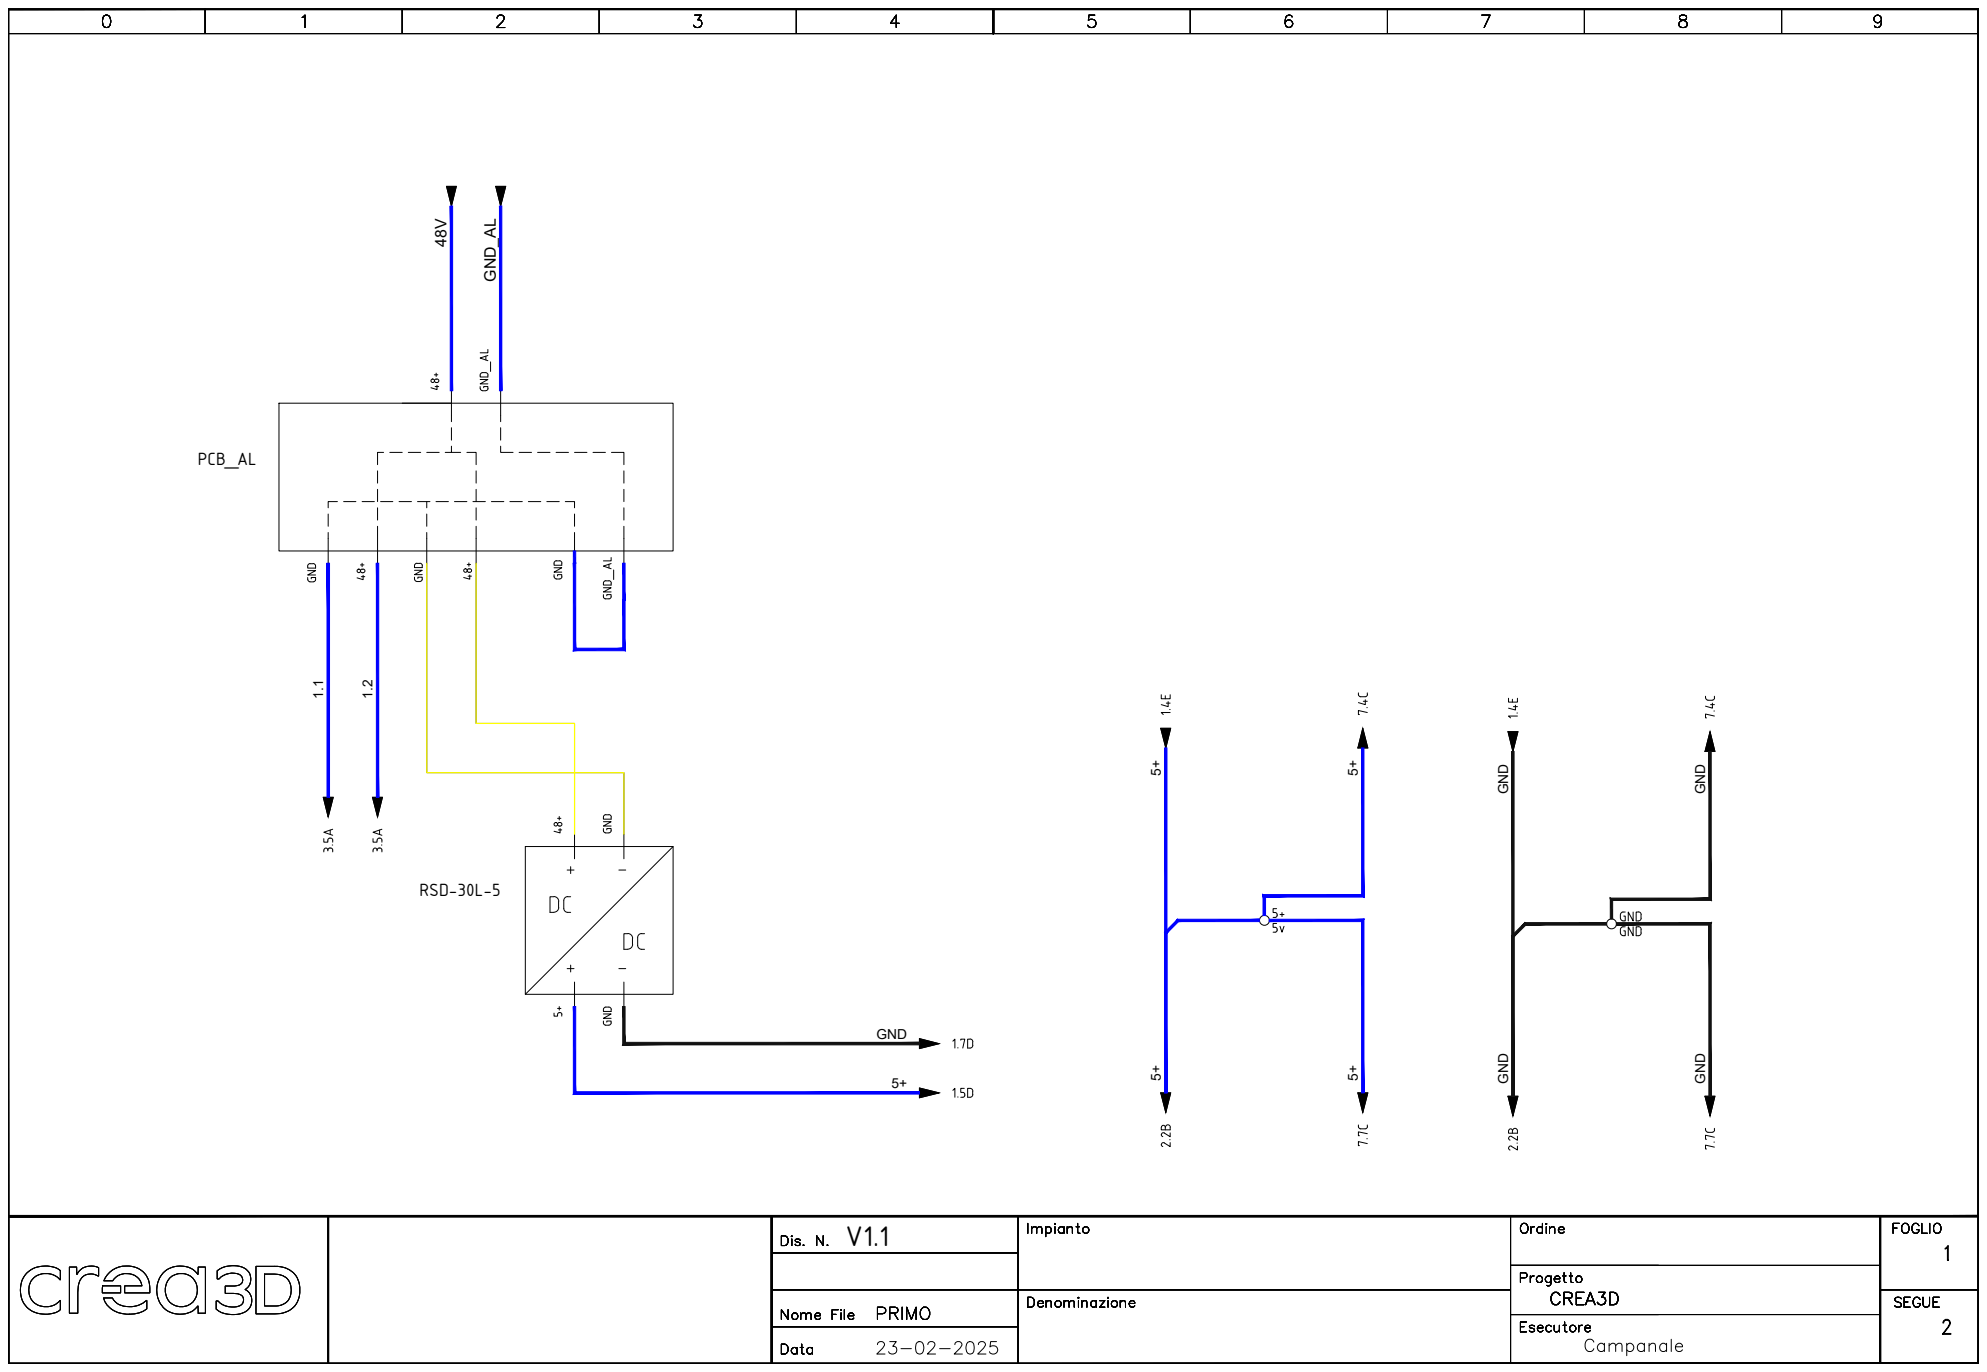
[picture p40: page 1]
RSD-30L-5; GND; GND GND; PCB_AL

# V1.1 ⁵⁺ GND

## FLAT

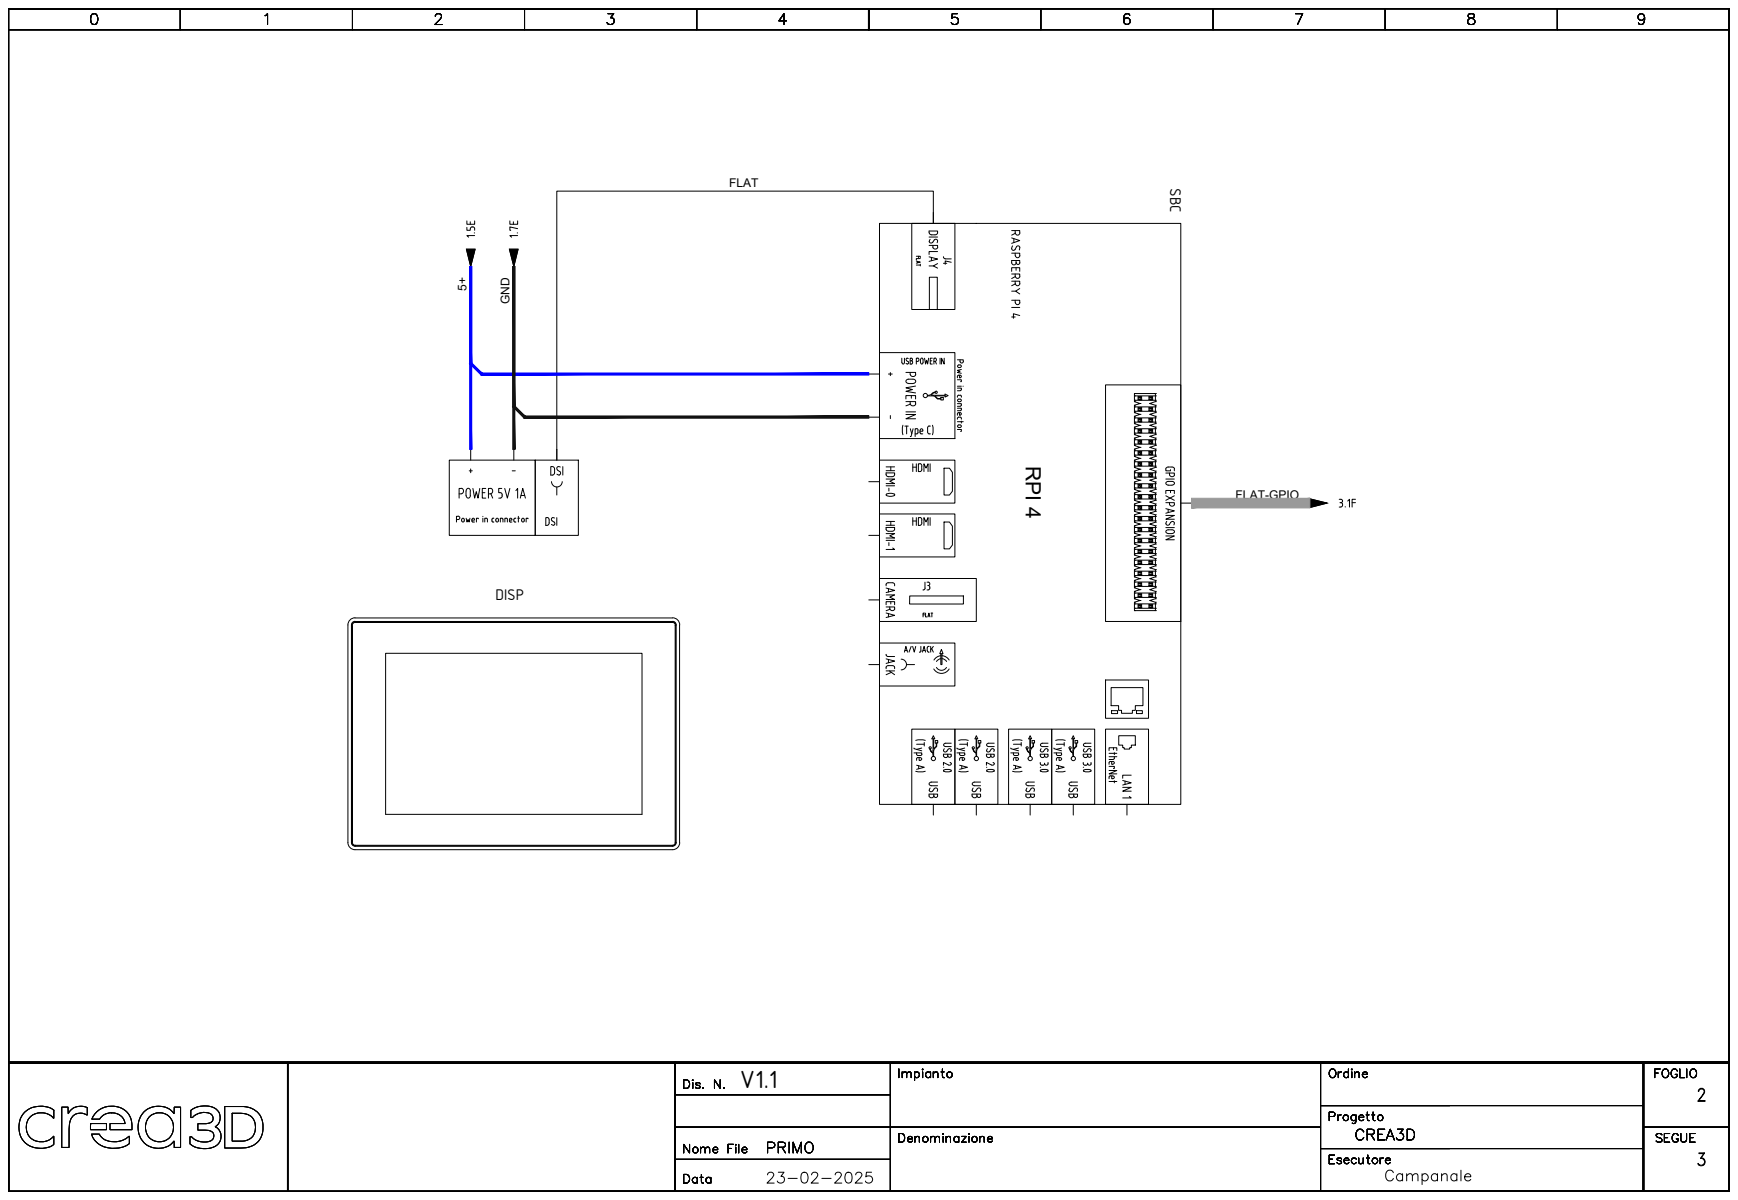
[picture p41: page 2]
RPI 4 SBC; DISP; FLAT-GPIO

## DI FLAT⁻GPIO

EM

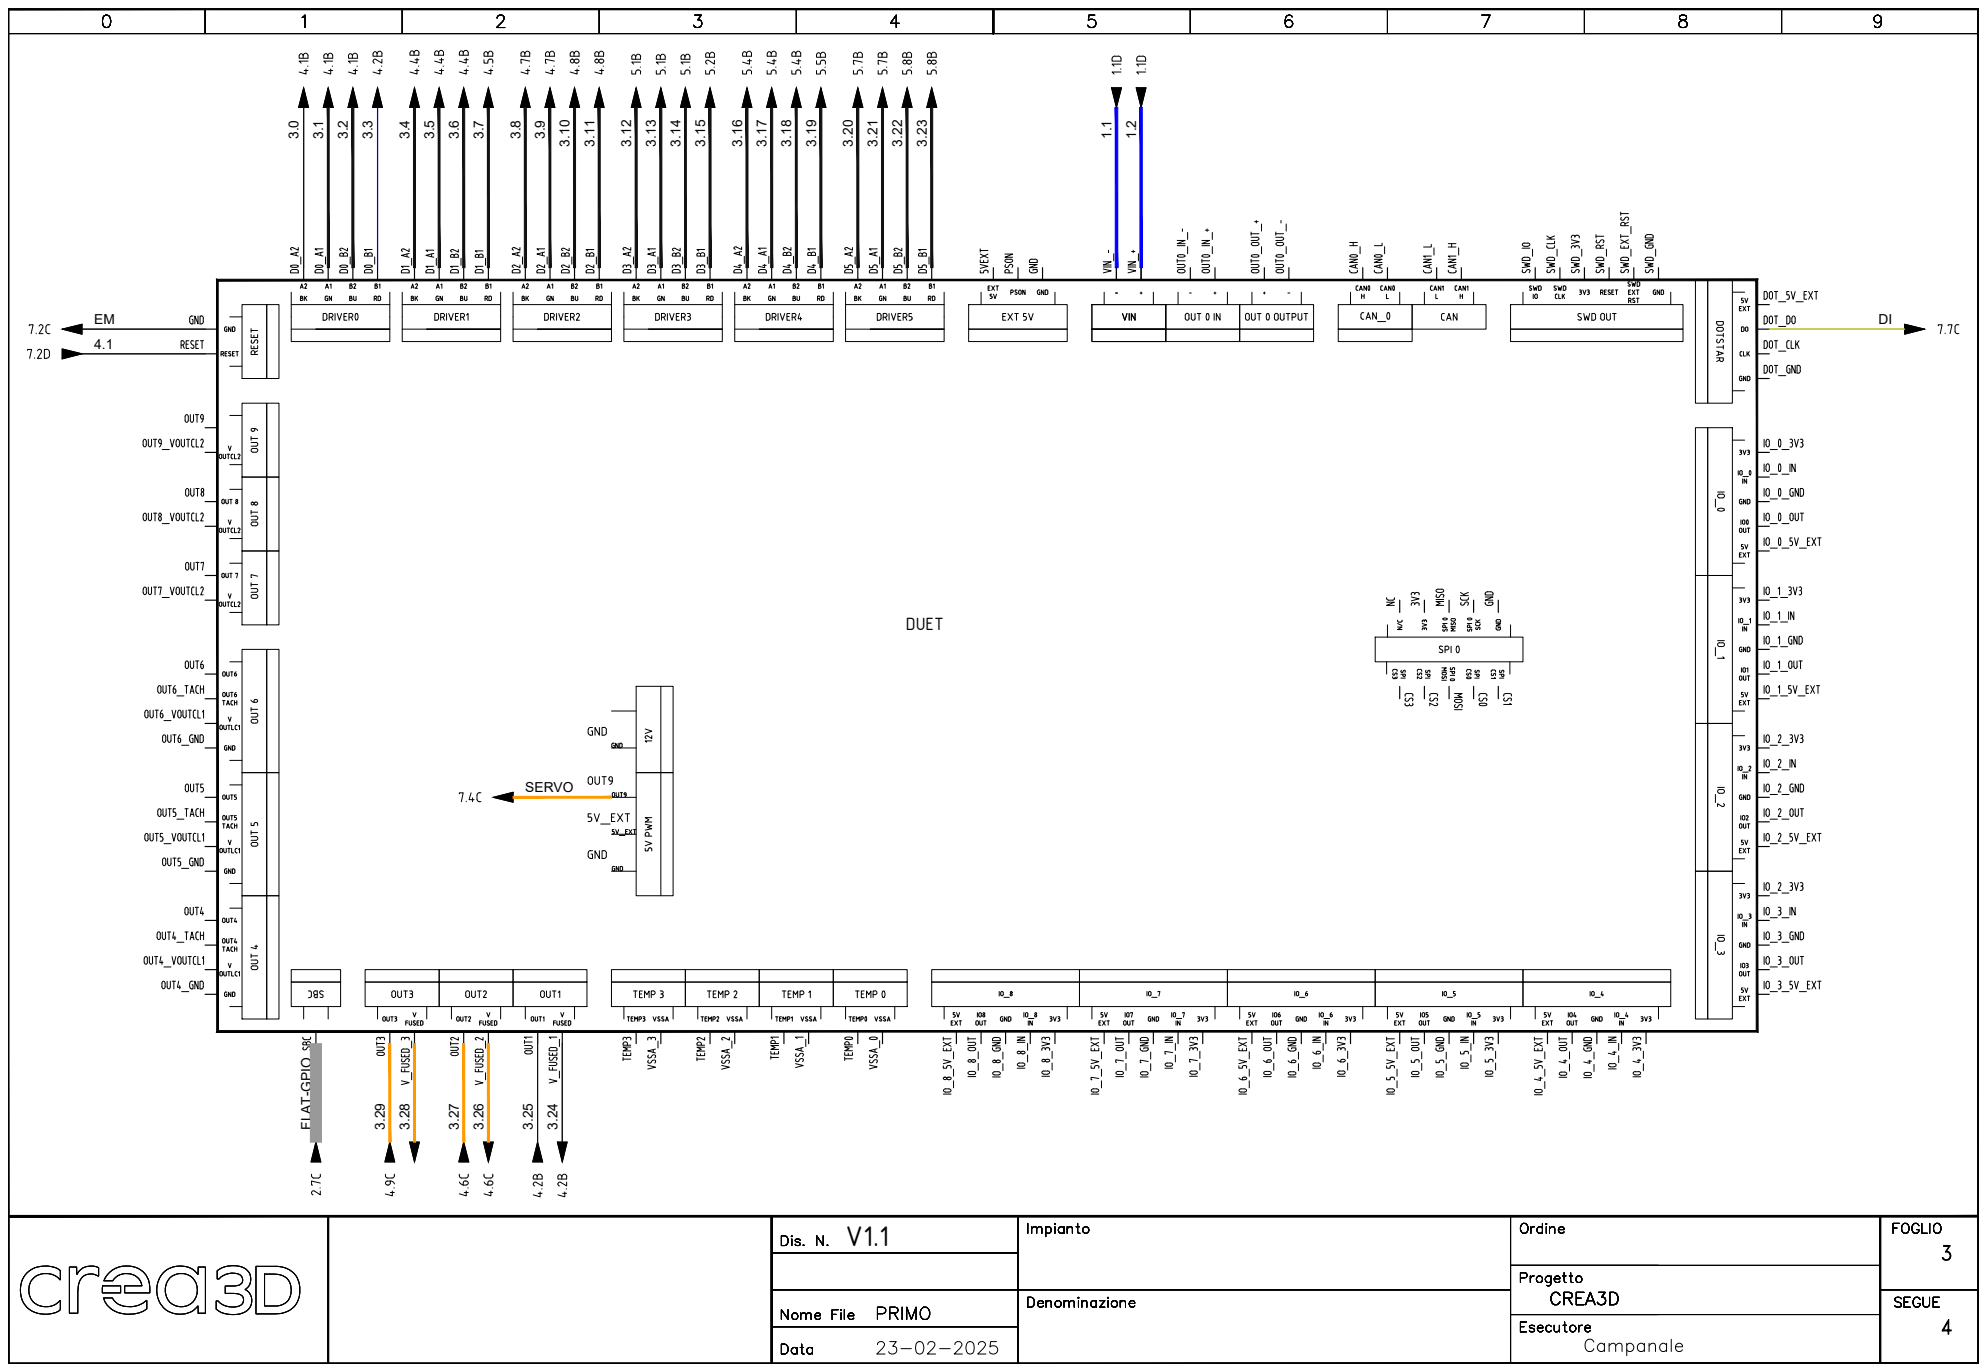
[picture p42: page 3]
SERVO; DUET ³.0

# PCBC ³.0 3.1

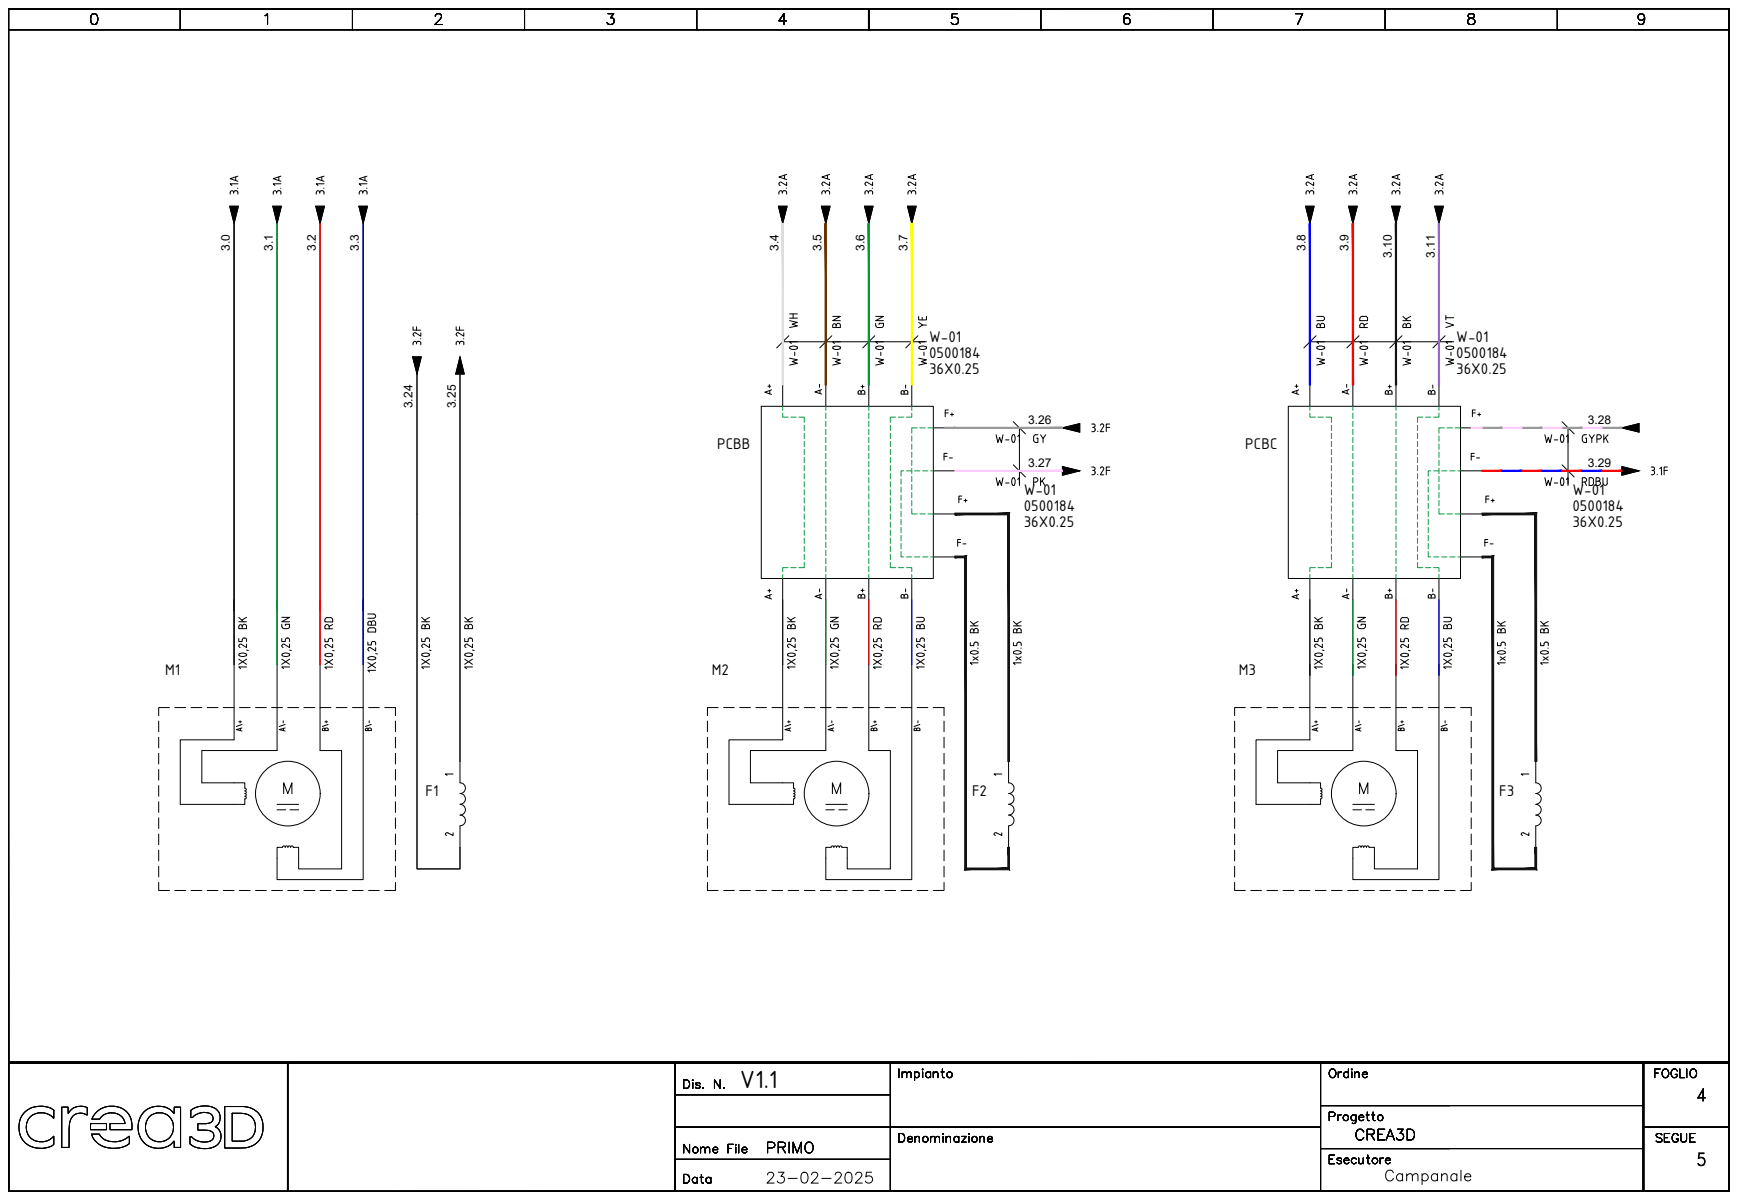
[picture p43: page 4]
PCBB

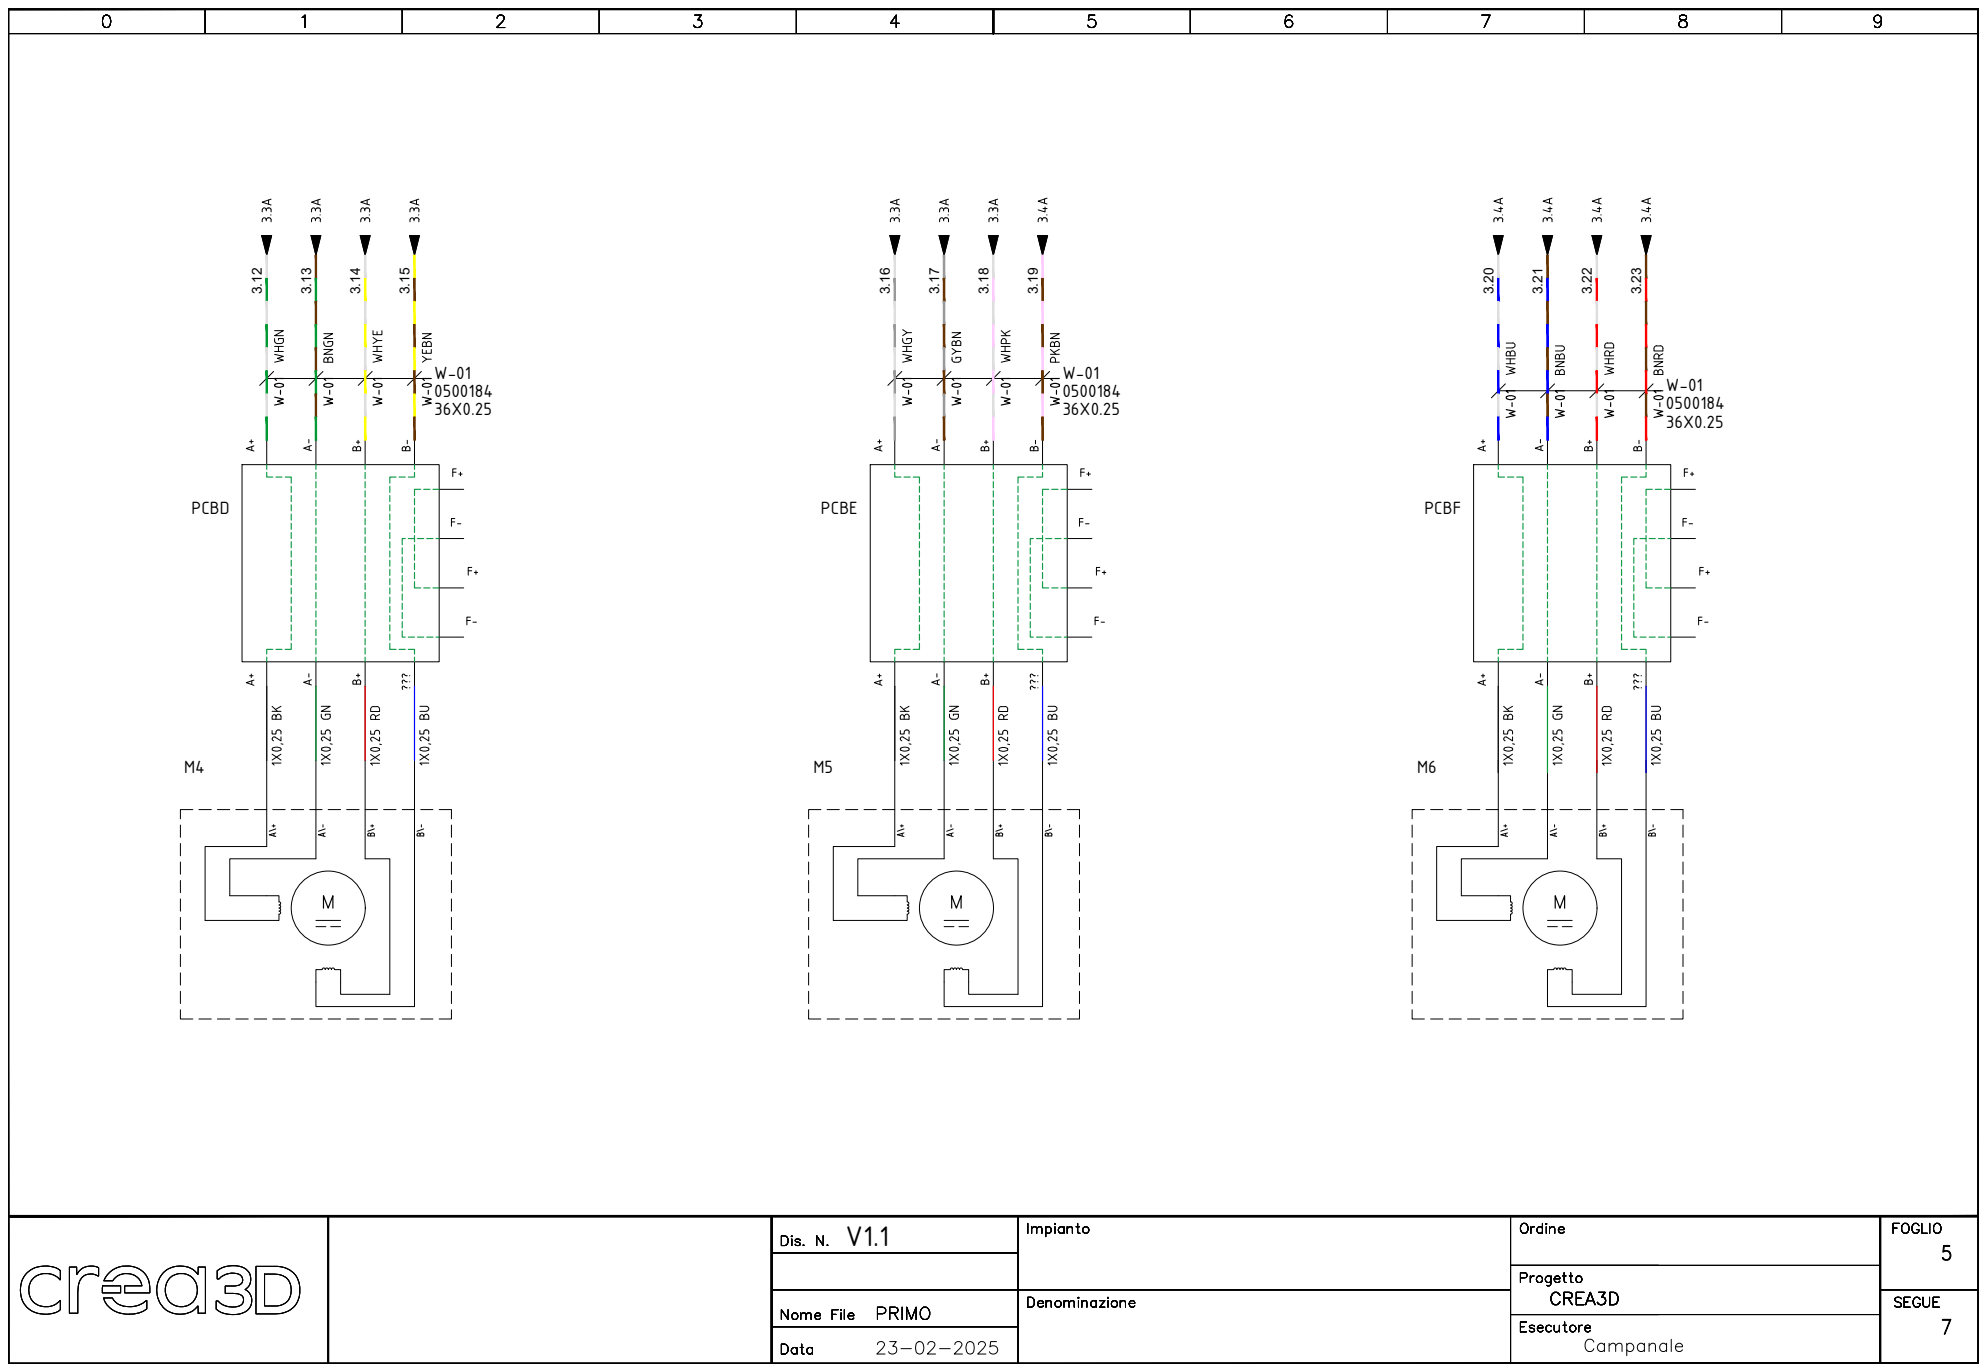
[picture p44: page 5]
PCBD; PCBE; PCBF ³.12

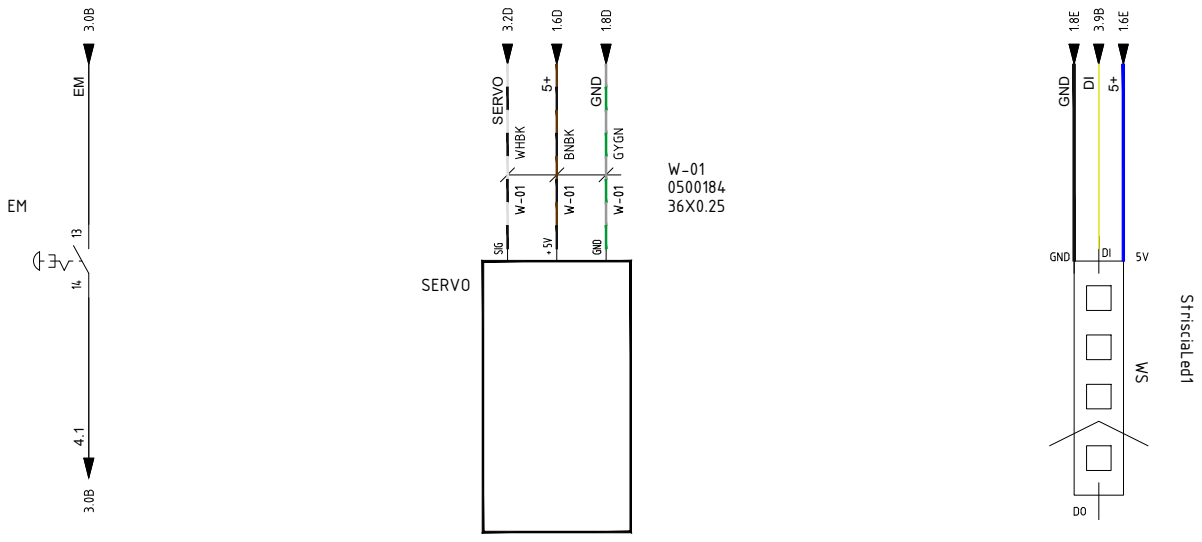
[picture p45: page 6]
SERVO; StrisciaLed1 5+; GND; 5+ SERVO

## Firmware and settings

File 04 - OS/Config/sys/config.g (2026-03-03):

; Configuration file for RepRapFirmware on Duet 3 Main Board 6HC
; executed by the firmware on start-up
;
; generated by RepRapFirmware Configuration Tool v3.5.4 on Mon Oct 14 2024 12:14:30 GMT+0200 (Ora legale dell’Europa centrale)



; General
G90                                                                  ; absolute coordinates
M83                                                                  ; relative extruder moves
M550 P"primo"                                                        ; set hostname

; Network
;M552 P0.0.0.0 S1 ; configure Ethernet adapter
;M586 P0 S1 ; configure HTTP

; Smart Drivers 2160
M569 P0.0 S0 D2                                                      ; driver 0.0 goes backwards (X axis)
M569 P0.1 S1 D2                                                      ; driver 0.1 goes forwards (Y axis)
M569 P0.2 S0 D2                                                      ; driver 0.2 goes backwards (Z axis)
M569 P0.3 S0 D2                                                      ; driver 0.3 goes backwards (A axis)
M569 P0.4 S1 D2                                                      ; driver 0.4 goes forwards (B axis)
M569 P0.5 S1 D2                                                      ; driver 0.5 goes backwards (C axis)

;Attivazione Driver
;M17 YZ

; Motor Idle Current Reduction
M906 I50                                                             ; set motor current idle factor
M917 X70 Y70 Z70 A70 B70 C70                                         ; Set motor standstill current reduction
;M84 S30 ; set motor current idle timeout

; Axes
M584 X0.0 Y0.1 Z0.2 A0.3 B0.4 C0.5                                   ; set axis mapping
M350 X4 Y4 Z4 A4 B4 C4 I1                                            ; configure microstepping with interpolation
M906 X1800 Y1800 Z1800 A1800 B1800 C1800                             ; set axis driver currents
M92 X14.222 Y177.778 Z180.952 A8.889 B8.889 C2.2222                  ; configure steps per mm
M208 X-160:160 Y-76:76 Z-55:90 A-156:156 B-134.5:134.5 C-153.3:153.3 ; set minimum and maximum axis limits MODIFICA: Z-60:90
M566 X10 Y500 Z500 A500 B500 C500                                   ; set maximum instantaneous acc changes (mm/min)
M203 X5000 Y3000 Z3000 A7000 B5000 C70000                             ; set maximum speeds (mm/min)
M201 X100 Y100 Z100 A100 B100 C100                                   ; set accelerations (mm/s^2)

; Kinematics
M669 K0

; Endstops
M574 X2 S3
M574 Y1 S3
M574 Z1 S3
M574 A2 S3
M574 B2 S3
M574 C2 S3

M915 X R0 F0

;Servo 
M950 S7 C"out9"

; Duet 3 led pin
M950 E0 C"led" T1                                                    ; create a RGB Dotstar 'led' strip on the LED port and set SPI frequency to 20kHz Q20000
;out0 5v
M950 P1 C"out0"                                                      ;
M950 P3 C"out1"                                                      ;
 
;Led Pulsante
;M950 P3 C"out7" ;
;M950 P4 C"out8" ; Crea un'uscita digitale su OUT8

;M950 J6 C"^!io0.in"; Configura il pulsante su IO_0
;M950 J5 C"^!io1.in"; Configura il pulsante su IO_1

;M581 P6 T1 S1; R0 ; Attiva l'interrupt su IO_0 per eseguire la macro trigger2.g al fronte di salita
;M581 P5 T3 S1; R0 ; Attiva l'interrupt su IO_0 per eseguire la macro trigger2.g al fronte di salita

; Stop
;M950 J1 C"io0.in"                   ; Definisce il pin per il pulsante
;global buttonPressCount = 0         ; Inizializza la variabile di stato
;M581 P1 T2 S1 R0                    ; Esegue l'interrupt trigger1.g al fronte di salita

;Ventola
;M308 S10 Y"drivers" A"Duet stepper drivers"  ; RICONTROLLA
;M950 F1 C"out7"     ; Definisci la ventola 1 collegata a OUT7 con una frequenza PWM di 500 Hz
;M106 P1 T40 H10     ; Accendi la ventola 1 la velocità della ventola scala da 0% a 100% quando la temperatura sale da 40°C a 70°C.


; Miscellaneous
M501                                                                 ; load saved parameters from non-volatile memory

;M98 P"0:/macros/5v/5vON";
